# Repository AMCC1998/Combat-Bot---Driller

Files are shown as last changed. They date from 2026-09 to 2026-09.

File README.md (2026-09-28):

# 🤖 Driller

**Driller** é um robô de combate da classe **Beetleweight (1,5 kg)** com arma do tipo **vertical spinner**, construído para competir na [Liga REC – Robot Extreme Competition](https://robotextreme.pt).

<p align="center">
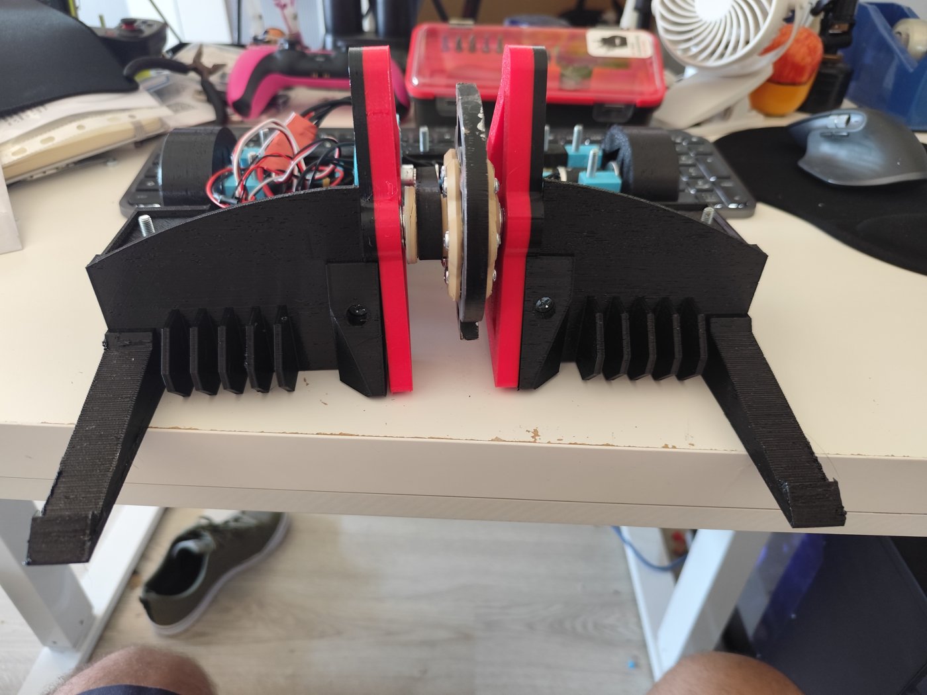
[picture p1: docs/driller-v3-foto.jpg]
Driller V3 em montagem
  
</p>

## 📍 Estado atual

| | |
|---|---|
| **Estado** | 🛠️ Em construção |
| **Versão atual** | V3 |
| **Próximo evento** | LGW (Lisboa Games Week) |
| **Peso** | Por confirmar na balança (limite: 1500 g, sem tolerância) |
| **Combates registados** | Ainda nenhum |

## 📐 Ficha técnica

| Item | Detalhe |
|---|---|
| Categoria | Beetleweight (1500 g) |
| Locomoção | Rodas (rolling), 2 motores |
| Arma | Vertical spinner (disco) |
| Motor da arma | RS2205 2300KV brushless |
| Motores de tração | 2× NEEBRC 2322 3500KV brushless + caixa redutora planetária 24 mm 16:1 |
| ESC da arma | ESC 30A com firmware AM32 |
| ESCs de tração | 2× ESC 20A com firmware AM32 (1 por motor, modo bidirecional) |
| Distribuição e interruptor | Placa de distribuição REC Lite, com interruptor por parafuso |
| Bateria | LiPo 3S 450 mAh |
| Rádio | HotRC |
| Chassis | Peças impressas em 3D; base em fibra de carbono 3 mm ou policarbonato 4 mm |

## 🧩 Lista de peças

| Peça | Modelo | Qtd | Peso unit. (g) | Preço unit. (€) | Fornecedor |
|---|---|:-:|:-:|:-:|---|
| Motor da arma | RS2205 2300KV brushless (CW/CCW) | 1 | ~30 | 6,10 | AliExpress |
| ESC da arma | ESC 30A AM32 | 1 | — | — | — |
| Motores de tração | NEEBRC 2322 3500KV brushless | 2 | ~50 | 15,00 | AliExpress |
| Caixas redutoras | Planetária 24 mm, 16:1 | 2 | ~45 | 15,00 | [Robot Extreme](https://robotextreme.pt) |
| ESCs de tração | ESC 20A AM32 | 2 | — | — | — |
| Placa de distribuição | REC Lite (interruptor por parafuso) | 1 | — | — | [Robot Extreme](https://robotextreme.pt) |
| Parafusos | DIN 7985 PZ M5×45 | — | — | — | INTEC |
| Parafusos | DIN 7985 PZ M4×16 | — | — | — | INTEC |
| Porcas | DIN 985 nyloc M5 | — | — | — | INTEC |

> Pesos marcados com `~` são estimativas, ainda por confirmar na balança.

## 🔄 Versões

O robô já passou por três iterações de design, cada uma na sua pasta:

| Versão | Período | Destaques nos ficheiros |
|---|---|---|
| **V1** | mar.–mai. 2026 | Primeira base e laterais, jantes e moldes para pneus, polia GT2 80T, tampa superior e proteção traseira |
| **V2** | jun.–jul. 2026 | Transmissão com carretos (motor/roda), novo disco da arma, suportes do disco com e sem rolamento, base em DXF para corte, proteções laterais e traseiras |
| **V3** ⭐ | set. 2026 | Versão atual: escudos frontais, jante com pneu integrado, laterais v2, novo topo e traseira, modelo 3D completo (`Driler V3.glb` / `.obj`) |

<p align="center">
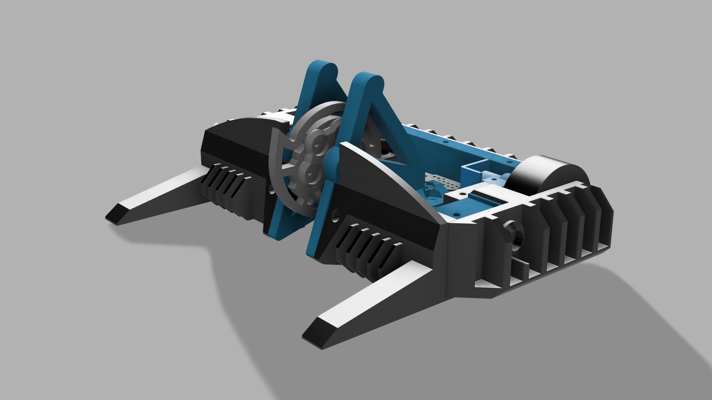
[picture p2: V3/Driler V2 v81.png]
Render do Driller V3
  
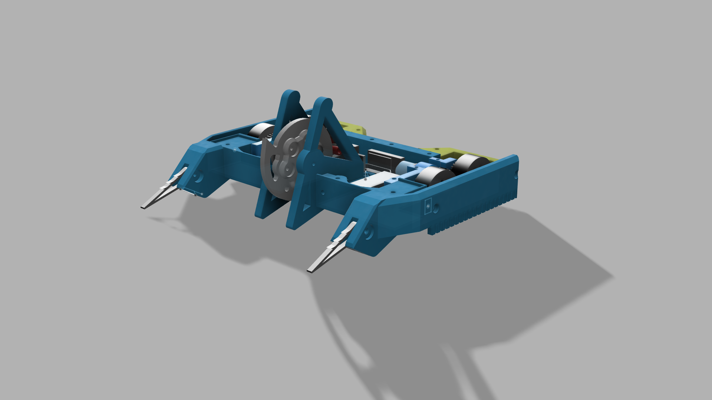
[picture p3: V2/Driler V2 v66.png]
Render do Driller V2
  
</p>
<p align="center"><em>À esquerda: render da V3. À direita: render da V2.</em></p>

## 📁 Estrutura do repositório

```
Driller/
├── V1/                            # Peças da 1.ª versão (STL)
├── V2/                            # Peças da 2.ª versão (STL, DXF, G-code, renders)
├── V3/                            # Versão atual (STL, G-code, renders, modelo 3D GLB/OBJ)
├── ESCs/                          # Firmware e configuração dos ESCs AM32
│   ├── AM32_GD32DEV_B_E230_2.20.hex
│   └── configuracoes_am32_config.ecf
├── akk-rs2205-2300kv-1.snapshot.1/  # Modelo 3D do motor RS2205 (STEP, F3D)
└── docs/                          # Imagens do README
```

## ⚡ ESCs (AM32)

Os ESCs usam firmware **AM32**:

- `ESCs/AM32_GD32DEV_B_E230_2.20.hex`: firmware AM32 v2.20 para ESCs com MCU GD32 (target `GD32DEV_B_E230`).
- `ESCs/configuracoes_am32_config.ecf`: configuração guardada com o AM32 Configurator.

Os ESCs de tração estão em modo bidirecional, para o robô andar para a frente e para trás. O ESC da arma roda num só sentido.

## 🛣️ Próximos passos

- [ ] Pesar todas as peças e confirmar a margem até aos 1500 g
- [ ] Melhorar o acesso à bateria sem ser preciso tirar toda a tampa superior
- [ ] Tornar o robô mais compacto
- [ ] Comparar os ESCs atuais com os B-CUBE AM32 45A (aquecimento e tamanho)

## 🏁 Competição

O Driller compete na **Liga REC**, na classe Beetleweight: 1500 g com a bateria instalada, sem tolerância. O robô é pesado na inspeção e antes de cada combate, e cada combate dura 3 minutos. Mais informação em [robotextreme.pt](https://robotextreme.pt).

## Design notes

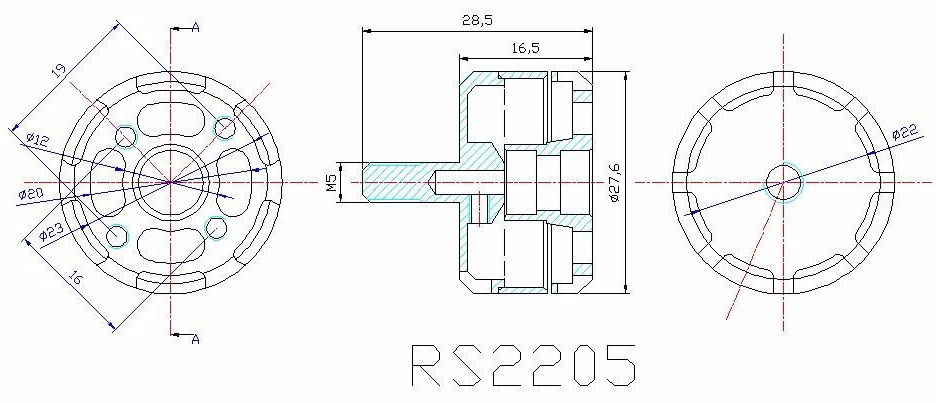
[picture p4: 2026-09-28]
akk-rs2205-2300kv-1.snapshot.1/readytosky-rs2205-1.snapshot.2/FCC287-6.jpg

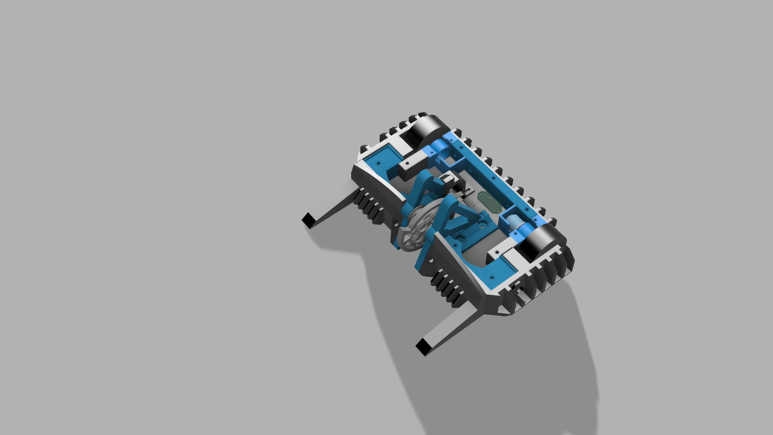
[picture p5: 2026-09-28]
V3/Driler V2 v82.png

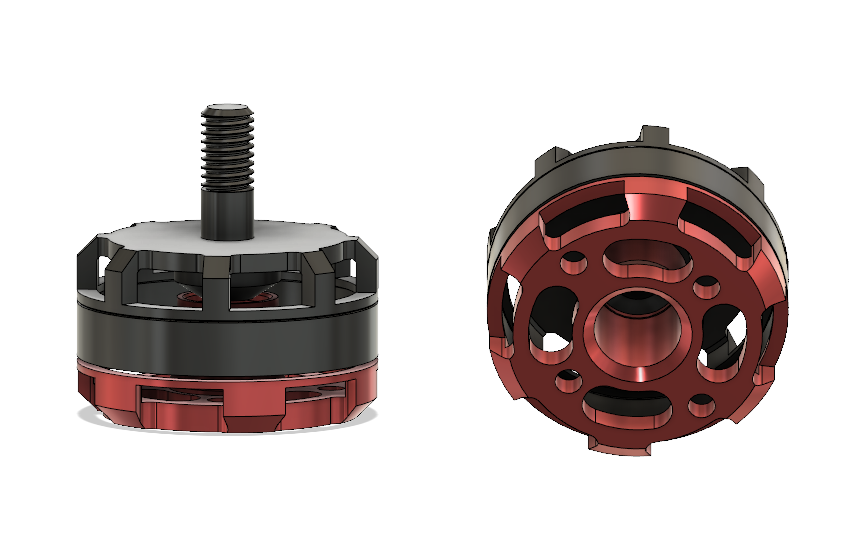
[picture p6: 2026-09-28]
akk-rs2205-2300kv-1.snapshot.1/readytosky-rs2205-1.snapshot.2/rs2205.png

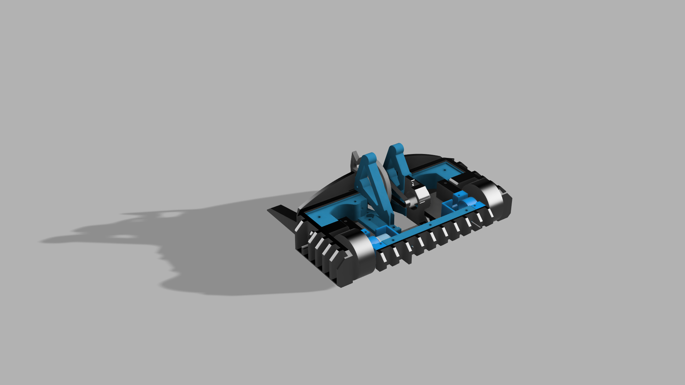
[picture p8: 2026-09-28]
V3/Driler V2 v83.png

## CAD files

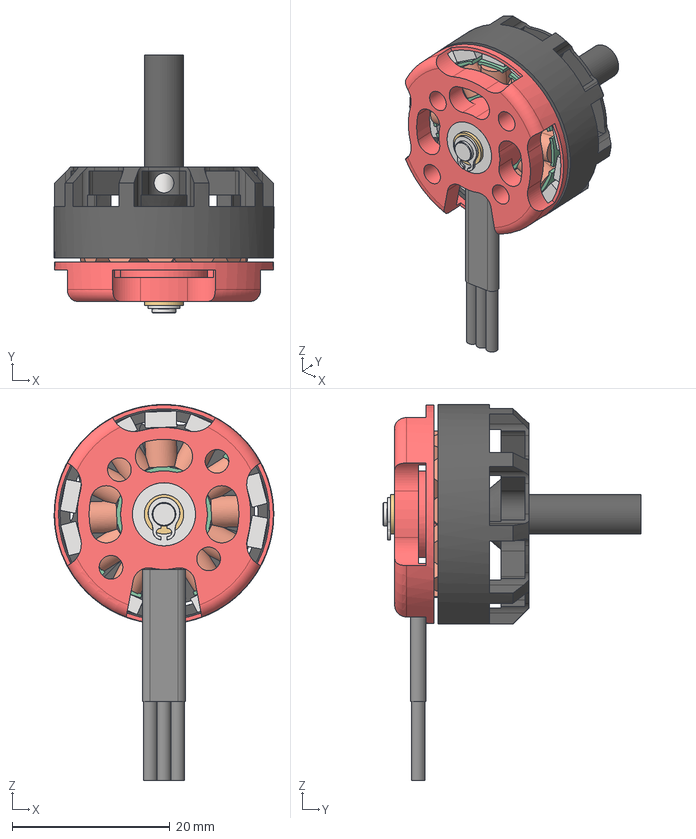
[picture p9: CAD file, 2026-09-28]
akk-rs2205-2300kv-1.snapshot.1/AKK RS2205 2300KV.stp
27.8 x 32.8 x 47.7 mm
BASE
BEARING x 2
STATOR
CAN
SHAFT
98541A111_External Retaining Ring
SPACER
COILS x 12
Magnets x 14
Cable Sleeve

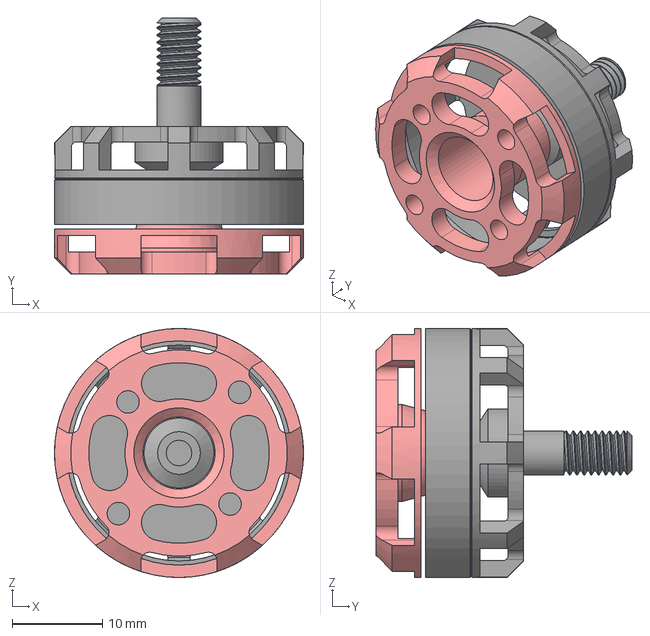
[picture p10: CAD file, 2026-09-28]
akk-rs2205-2300kv-1.snapshot.1/readytosky-rs2205-1.snapshot.2/RS2205 Readytosky.step
27.6 x 28.4 x 27.6 mm

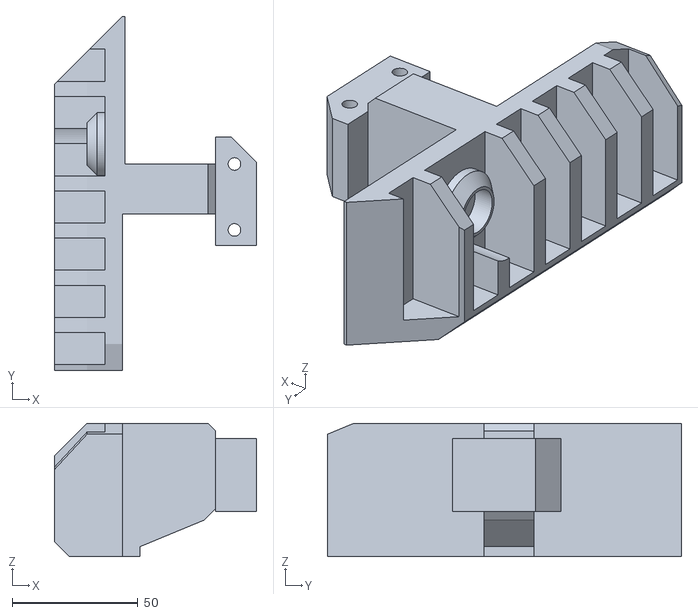
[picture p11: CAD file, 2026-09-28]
V3/lateral_esq_v2.stl
80.3 x 140.6 x 53.0

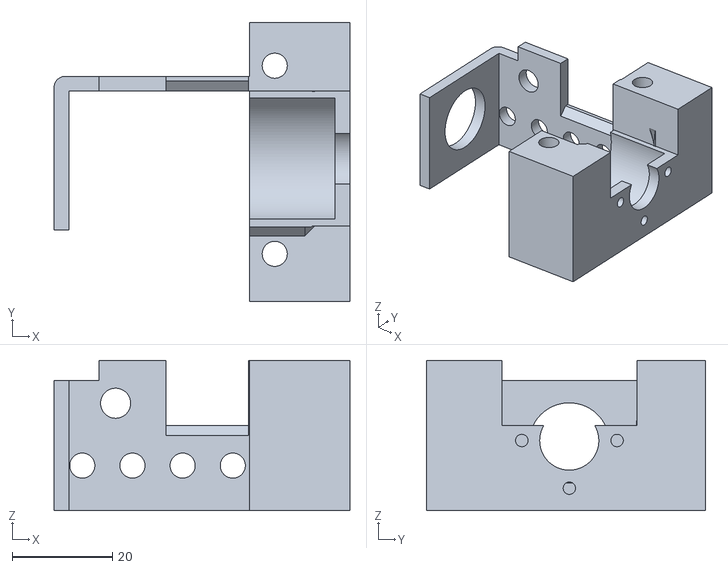
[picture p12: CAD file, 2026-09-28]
V3/Suporte_motor_dir.stl
59.0 x 55.6 x 30.0

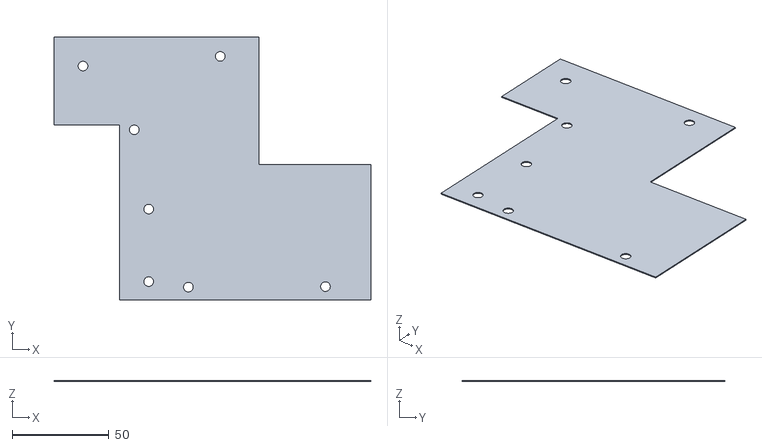
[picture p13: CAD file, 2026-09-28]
V3/base_model_2.stl
164.0 x 136.0 x 0.5

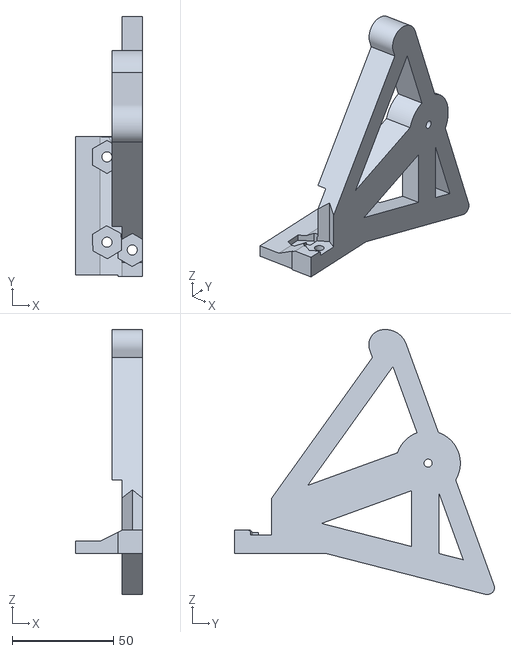
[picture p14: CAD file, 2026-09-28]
V3/braco_disco (1).stl
33.0 x 128.6 x 131.1

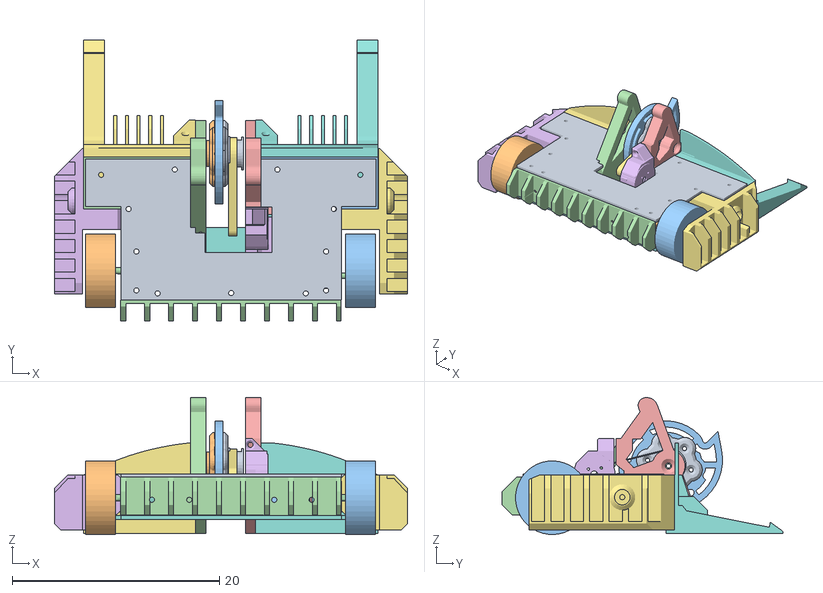
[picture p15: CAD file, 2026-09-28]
V3/Driler V3.obj
34.0 x 27.1 x 13.2
suporte_disco_rolamento
suporte_disco_sem_rolamento
Dsico_arma_1 (1)
braco_disco (1)
braco_disco (1) (1) (1) (4) (2)
Suporte_motor
Correia
topo
Suporte_motor_esq (1)
Suporte_motor_dir
lat_dir_interior
lat_esq_interior
traseira
lateral_esq_v2
lateral_dir_v2
escudo_frente_esq
escudo_frente_dir
topo:1
protecao_traseira

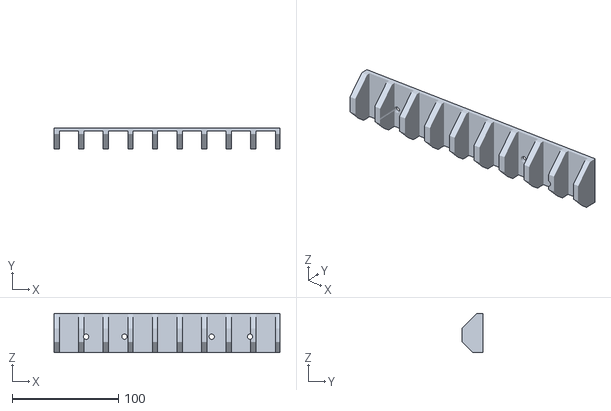
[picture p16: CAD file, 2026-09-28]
V3/protecao_traseira.stl
212.4 x 20.0 x 36.9

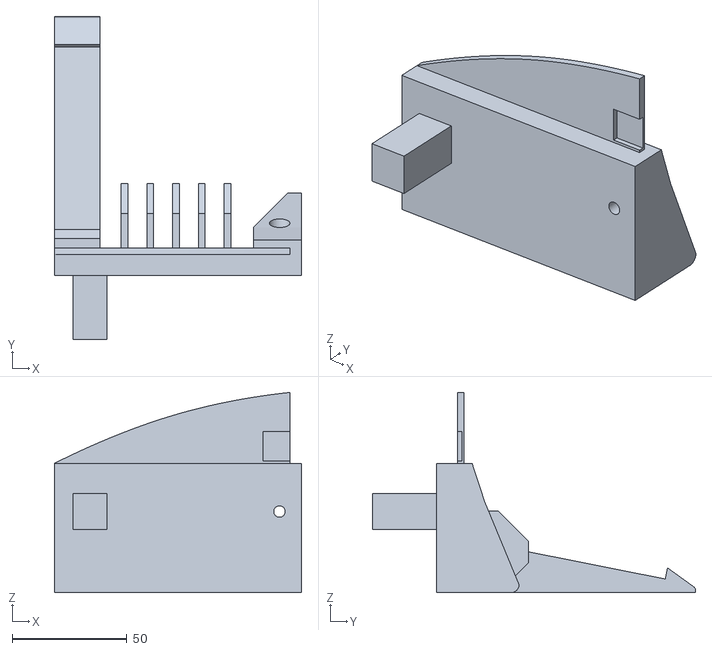
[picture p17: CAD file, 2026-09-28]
V3/escudo_frente_esq.stl
108.0 x 141.0 x 87.4

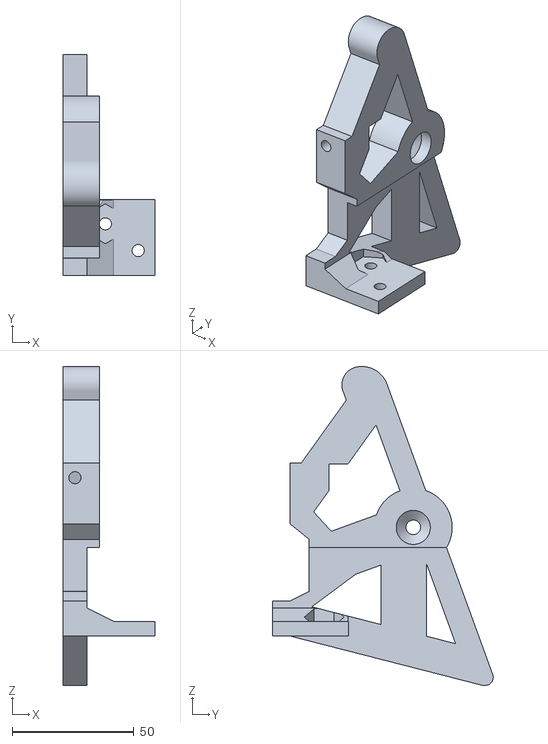
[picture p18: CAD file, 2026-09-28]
V3/braco_disco (1) (1) (1) (4) (2).stl
38.0 x 90.6 x 131.1

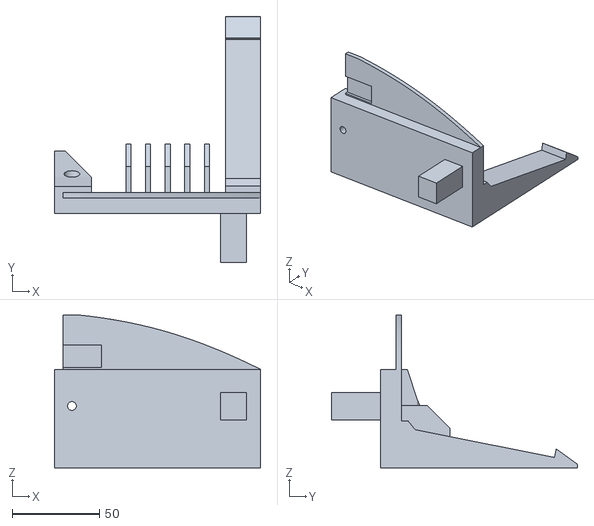
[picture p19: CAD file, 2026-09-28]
V3/escudo_frente_dir.stl
118.0 x 141.0 x 87.4

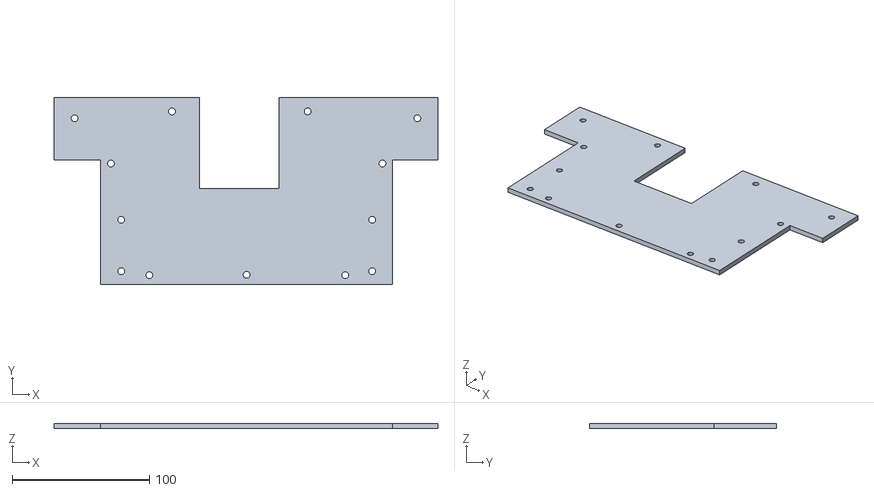
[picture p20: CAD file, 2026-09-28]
V3/topo.stl
280.0 x 136.0 x 4.00

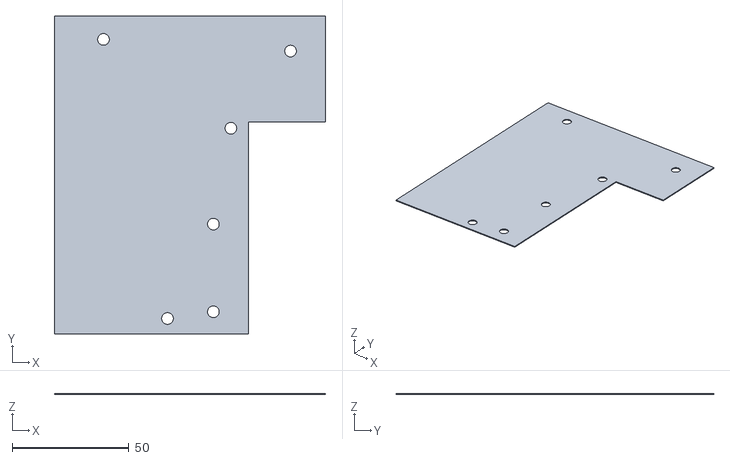
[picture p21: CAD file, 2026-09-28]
V3/base_modelo.stl
116.0 x 136.0 x 0.5

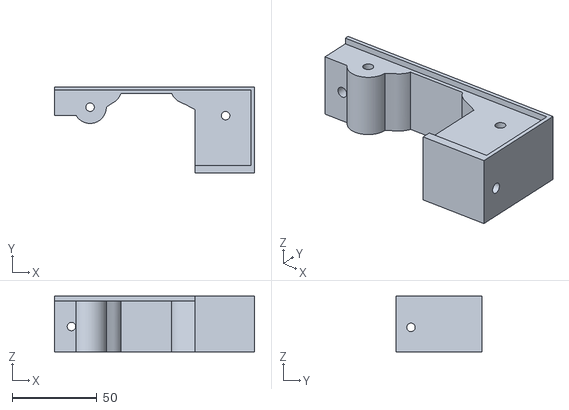
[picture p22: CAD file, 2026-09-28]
V3/lat_dir_interior.stl
118.0 x 50.9 x 33.0

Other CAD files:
V3/lateral_dir_v2.stl
V3/jante_com_pneu.stl
V3/lat_esq_interior.stl
V3/Suporte_motor_esq (1).stl
V1/Body23.stl
V1/Body55.stl
V1/Body65.stl
V1/Body71.stl
V1/Body72.stl
V1/Body90.stl
V1/Body91.stl
V1/JANTE.stl
V1/Lateral Esq.stl
V1/Polia.stl
V1/Tampa Superior (1).stl
V1/Tampa Superior.stl
V1/base (1).stl
V1/base disco 2.stl
V1/base.stl
V1/jante (1).stl
V1/jante_tpu.stl
V1/lateral_dir.stl
V1/lateral_dir_frente.stl
V1/lateral_disco_dir.stl
V1/lateral_disco_esq.stl
V1/lateral_esq_frente.stl
V1/molde_pneu_cima (1).stl
V1/molde_pneu_cima.stl
V1/polia_elgin_gt2_80t.stl
V1/protecao_tras.stl
V1/tras.stl
V2/Body129.stl
V2/Disco_arma_1.stl
V2/Suporte_motor_dir.stl
V2/Suporte_motor_esq (1) (1).stl
V2/Suporte_motor_esq (1).stl
V2/base.dxf
V2/braco_disco_direito.stl
V2/carreto_motor.stl
V2/carreto_roda.stl
V2/jante.stl
V2/lat_dir_interior.stl
V2/lat_esq_interior.stl
V2/molde_paneu_cima (1).stl
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
